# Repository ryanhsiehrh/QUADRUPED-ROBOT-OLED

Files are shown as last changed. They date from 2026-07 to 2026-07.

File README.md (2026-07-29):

# QUADRUPED-ROBOT-OLED
Quadruped robot powered by an Arduino Pro Micro (ATmega32U4). Operates on 5V power, utilizing 12 servo motors for inverse kinematics and an animated OLED display face through Software I2C.


##  What it does

* **Inverse Kinematics:** Calculates real-time 3D leg positions ($X, Y, Z$) across 12 servos (3 per leg) for smooth walking, turning, and custom body movements.
* **Animated OLED Face:** Runs an expression state machine on a 0.96 inch OLED display. The eyes pan side-to-side, blink every 3 seconds, and automatically close when the robot sits down.
* **Software I2C Communication:** Since the Pro Micro's hardware I2C pins (Pins 2 & 3) were already being used for servo signal lines, the OLED screen is driven via software I2C on analog pins `A0` (SDA) and `A1` (SCL).
* **50Hz Servo Interrupts:** Uses `FlexiTimer2` to keep servo updates running smoothly in the background without locking up the loop.
* **USB Serial Control:** Responds to string commands sent from the Arduino Serial Monitor at 9600 baud.

---

##  Hardware Setup & Pin Mapping

### Electronics
* **Board:** Arduino Pro Micro (ATmega32U4, 5V / 16MHz)
* **Servos:** 12x SG90 Micro Servos
* **Display:** 0.96" SSD1306 OLED Screen ($128 \times 64$, Yellow/Blue split)
* **Power:** External 5V power supply for the servos (common ground connected to the Arduino).
* **LM2596S Step Down Module** used to step down 12V power supply to 5V if needed

### Pinout Table

| Component | Function | Arduino Pro Micro Pin |
| :--- | :--- | :--- |
| **OLED Display** | **SDA** (Data) | **A0** *(Software I2C)* |
| **OLED Display** | **SCL** (Clock) | **A1** *(Software I2C)* |
| **Leg 0 (Back Left)** | Coxa / Femur / Tibia | Pins `2`, `3`, `4` |
| **Leg 1 (Front Left)**| Coxa / Femur / Tibia | Pins `5`, `6`, `7` |
| **Leg 2 (Back Right)** | Coxa / Femur / Tibia | Pins `8`, `9`, `10` |
| **Leg 3 (Front Right)**  | Coxa / Femur / Tibia | Pins `16`, `14`, `15` |

---

## PCB Design

* Simple 2-layer design with a solid ground plane on the back
* Uses barrel jack for power connection
* Specific area to hold the LM2596S Step Down Module
* Contains SPDT switch to toggle power to servo motors ON or OFF

**Schematic:**

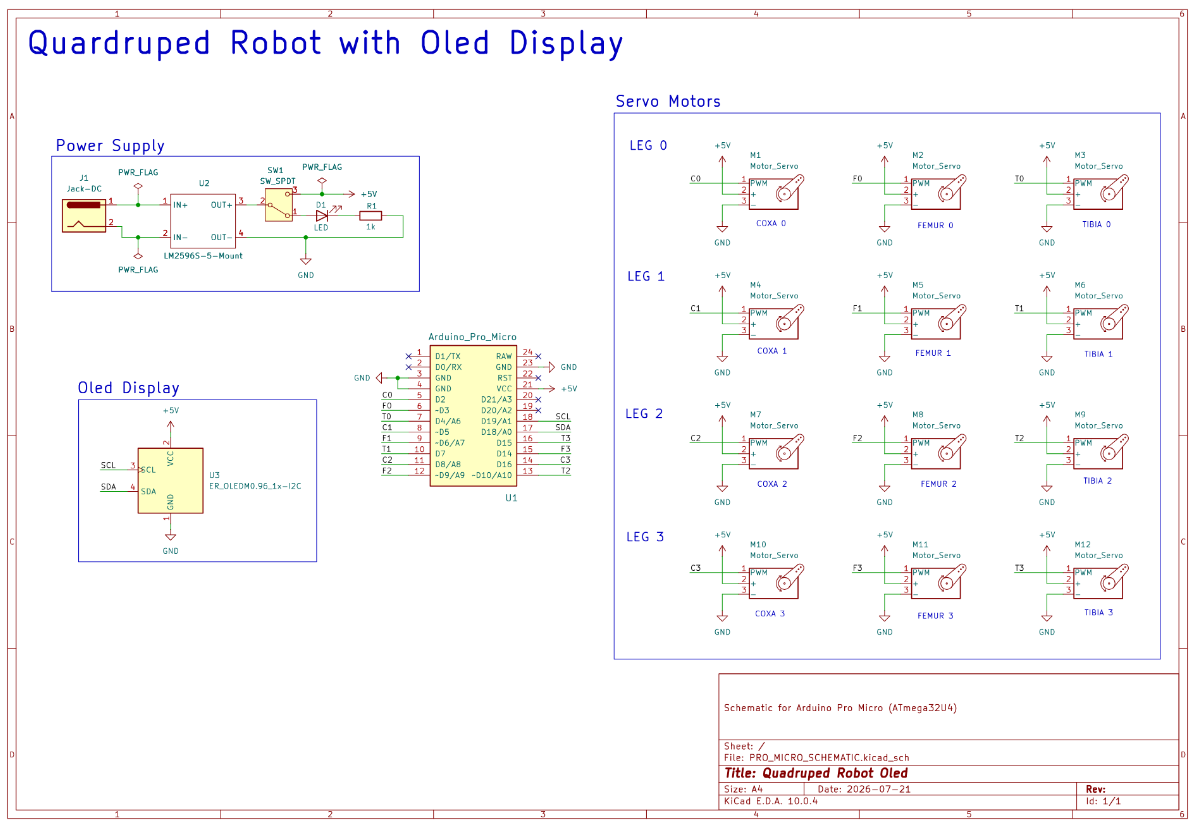
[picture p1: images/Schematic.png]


**PCB:**

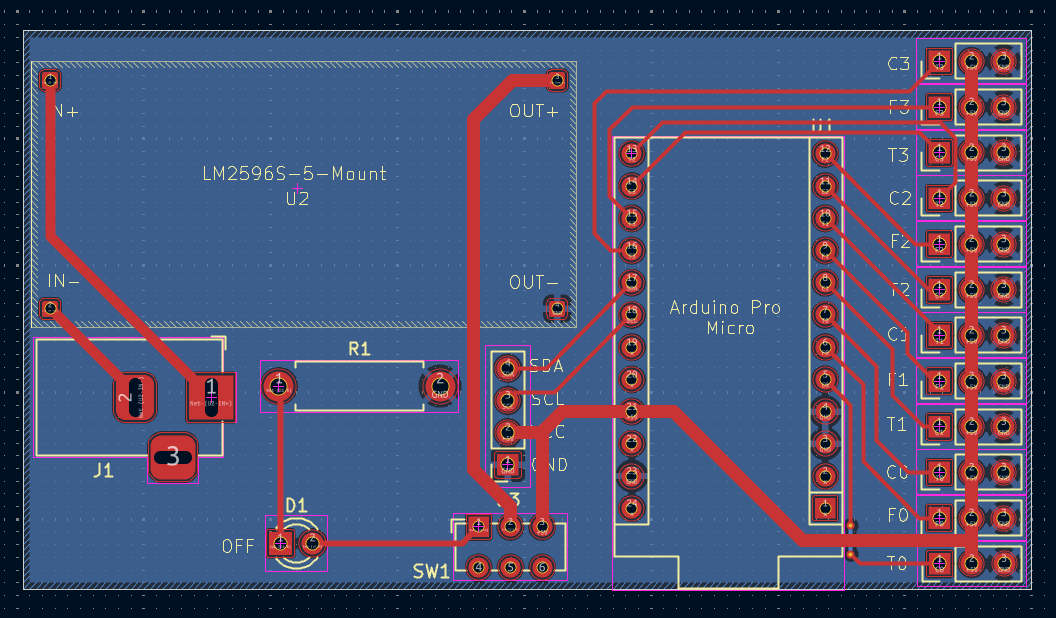
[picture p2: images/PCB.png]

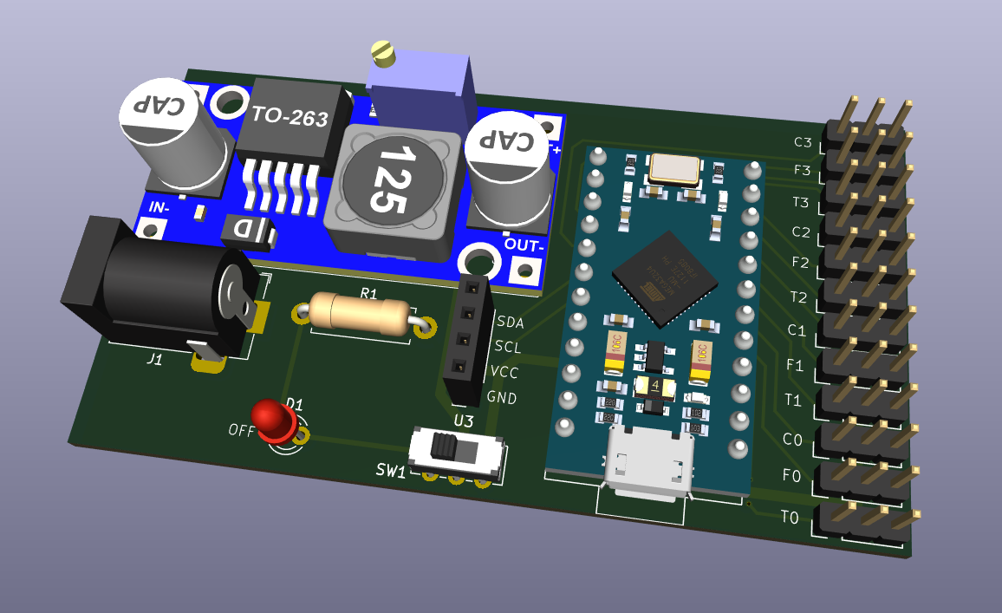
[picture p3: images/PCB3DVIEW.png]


---

##  Serial Commands

Set your Serial Monitor to **9600 Baud** and **Newline**. Type any of the following commands:

* `w 0 1` – Stand Up (wakes up face display)
* `w 0 0` – Sit Down (closes eyes on display)
* `w 1 x` – Walk Forward x steps
* `w 2 x` – Walk Backward x steps
* `w 3 x` – Turn Right x steps
* `w 4 x` – Turn Left x steps
* `w 5 x` – Hand Shake emote (x times)
* `w 6 x` – Hand Wave emote (x times)
* `w 7 x` – Side-to-Side body sway (x times)
* `w 8 x` – Bounce body emote (x times)
* `w 9 x` – Up and Down stretch (x times)

---

## Libraries

Install these via the Arduino Library Manager or online:

* `U8g2` (for operating OLED screen)
* `FlexiTimer2` (for 50Hz timer interrupts)
* `SerialCommand` (for parsing serial input strings)
* `Servo` (standard servo motor library)

---

## 3D Printed Parts

The chassis and leg components are based on [Regis Hsu's Spider Robot Design on Thingiverse](https://www.thingiverse.com/thing:1009659).

---

## How to Run

1. **Center Servos:** Before attaching the legs, upload `servo_90.ino` to set all 12 servos to their $90^\circ$ midpoint.
2. **Assemble:** Mount the leg horns at $90^\circ$ angles relative to the chassis.
3. **Upload Firmware:** Open `QUADRUPED-ROBOT-OLED.ino`, select **Arduino Leonardo**, and flash the sketch.
4. **Test:** Open Serial Monitor, make sure Newline is enabled, and send `w 0 1` to stand the robot up!

---

## Demo Video
[Watch the Quadruped Robot video here!](https://www.youtube.com/watch?v=7HYvcp7Kx8c)

---

## Credits

* Original base code by panerqiang@sunfounder.com (2015).
* Bluetooth remote and emote modifications by **RegisHsu** (2015).
* Pro Micro migration, custom movement emotes, software I2C OLED face animation, Kicad schematic and PCB developed by **Ryan Hsieh**.

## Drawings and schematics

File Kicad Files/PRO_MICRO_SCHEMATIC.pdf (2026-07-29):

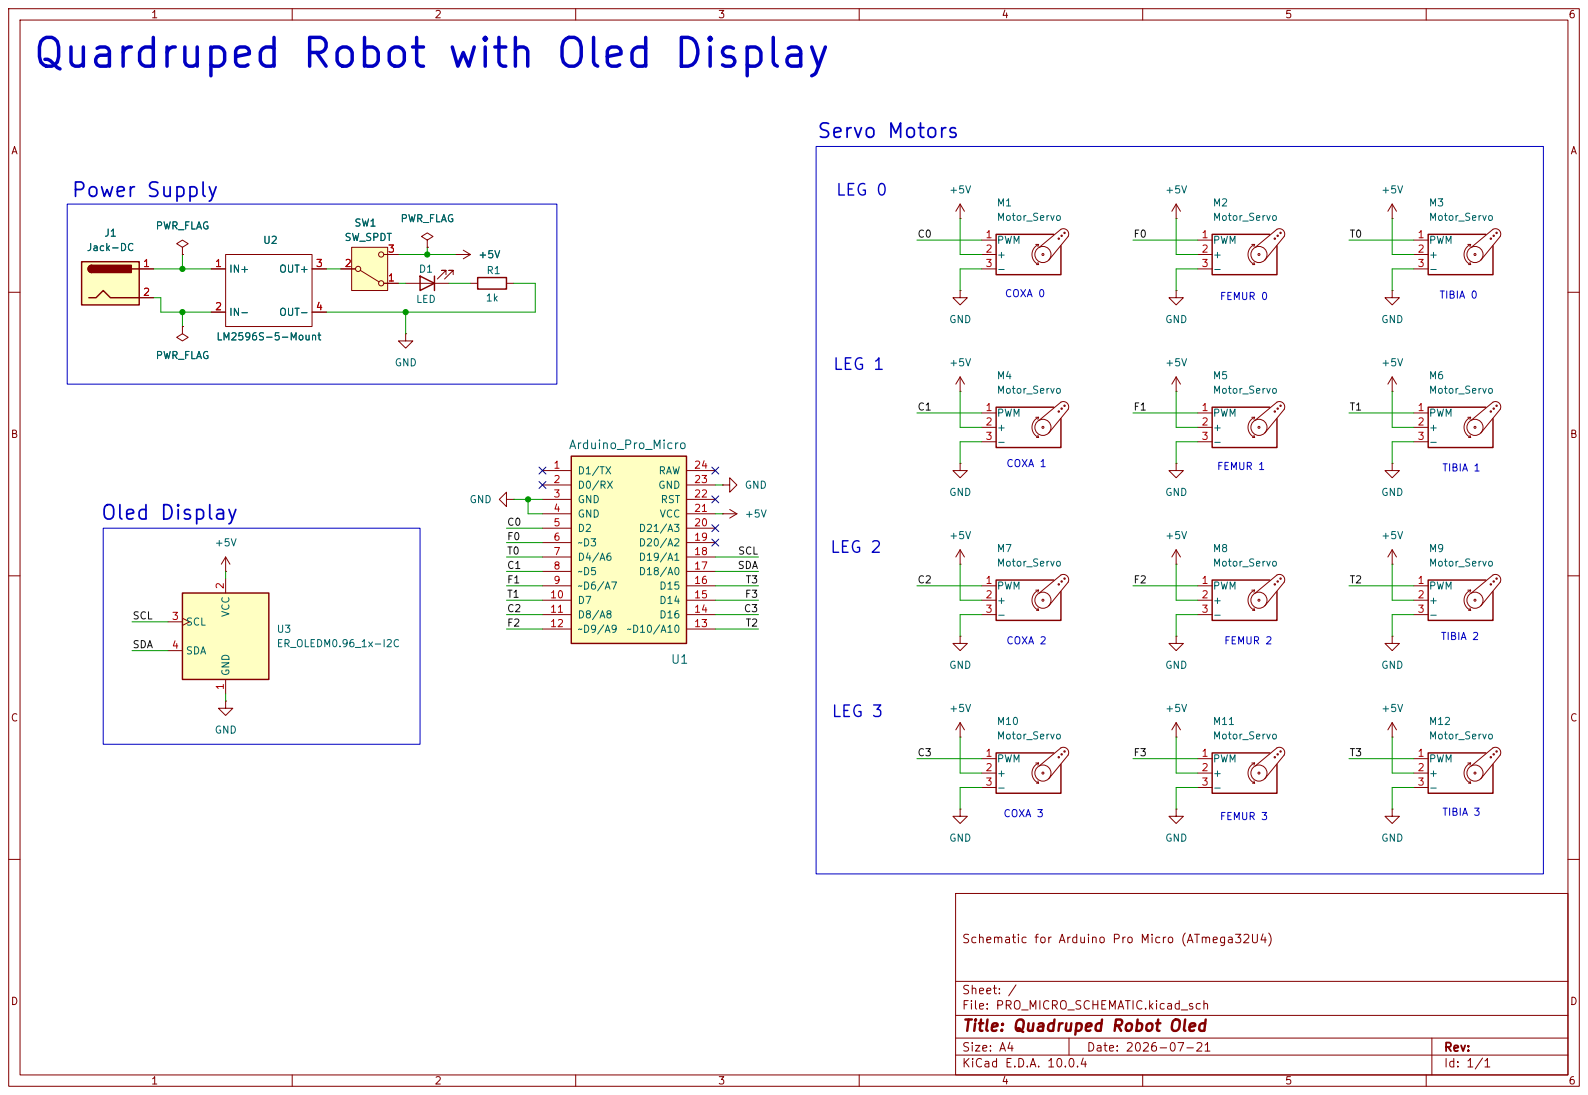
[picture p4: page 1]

F2 SCL Quardruped Robot with Oled Display

Schematic for Arduino Pro Micro (ATmega32U4)

Sheet: /
File: PRO_MICRO_SCHEMATIC.kicad_sch
Title: Quadruped Robot Oled

Size: A4 | Rev:
KiCad E.D.A. 10.0.4 | Id: 1/1

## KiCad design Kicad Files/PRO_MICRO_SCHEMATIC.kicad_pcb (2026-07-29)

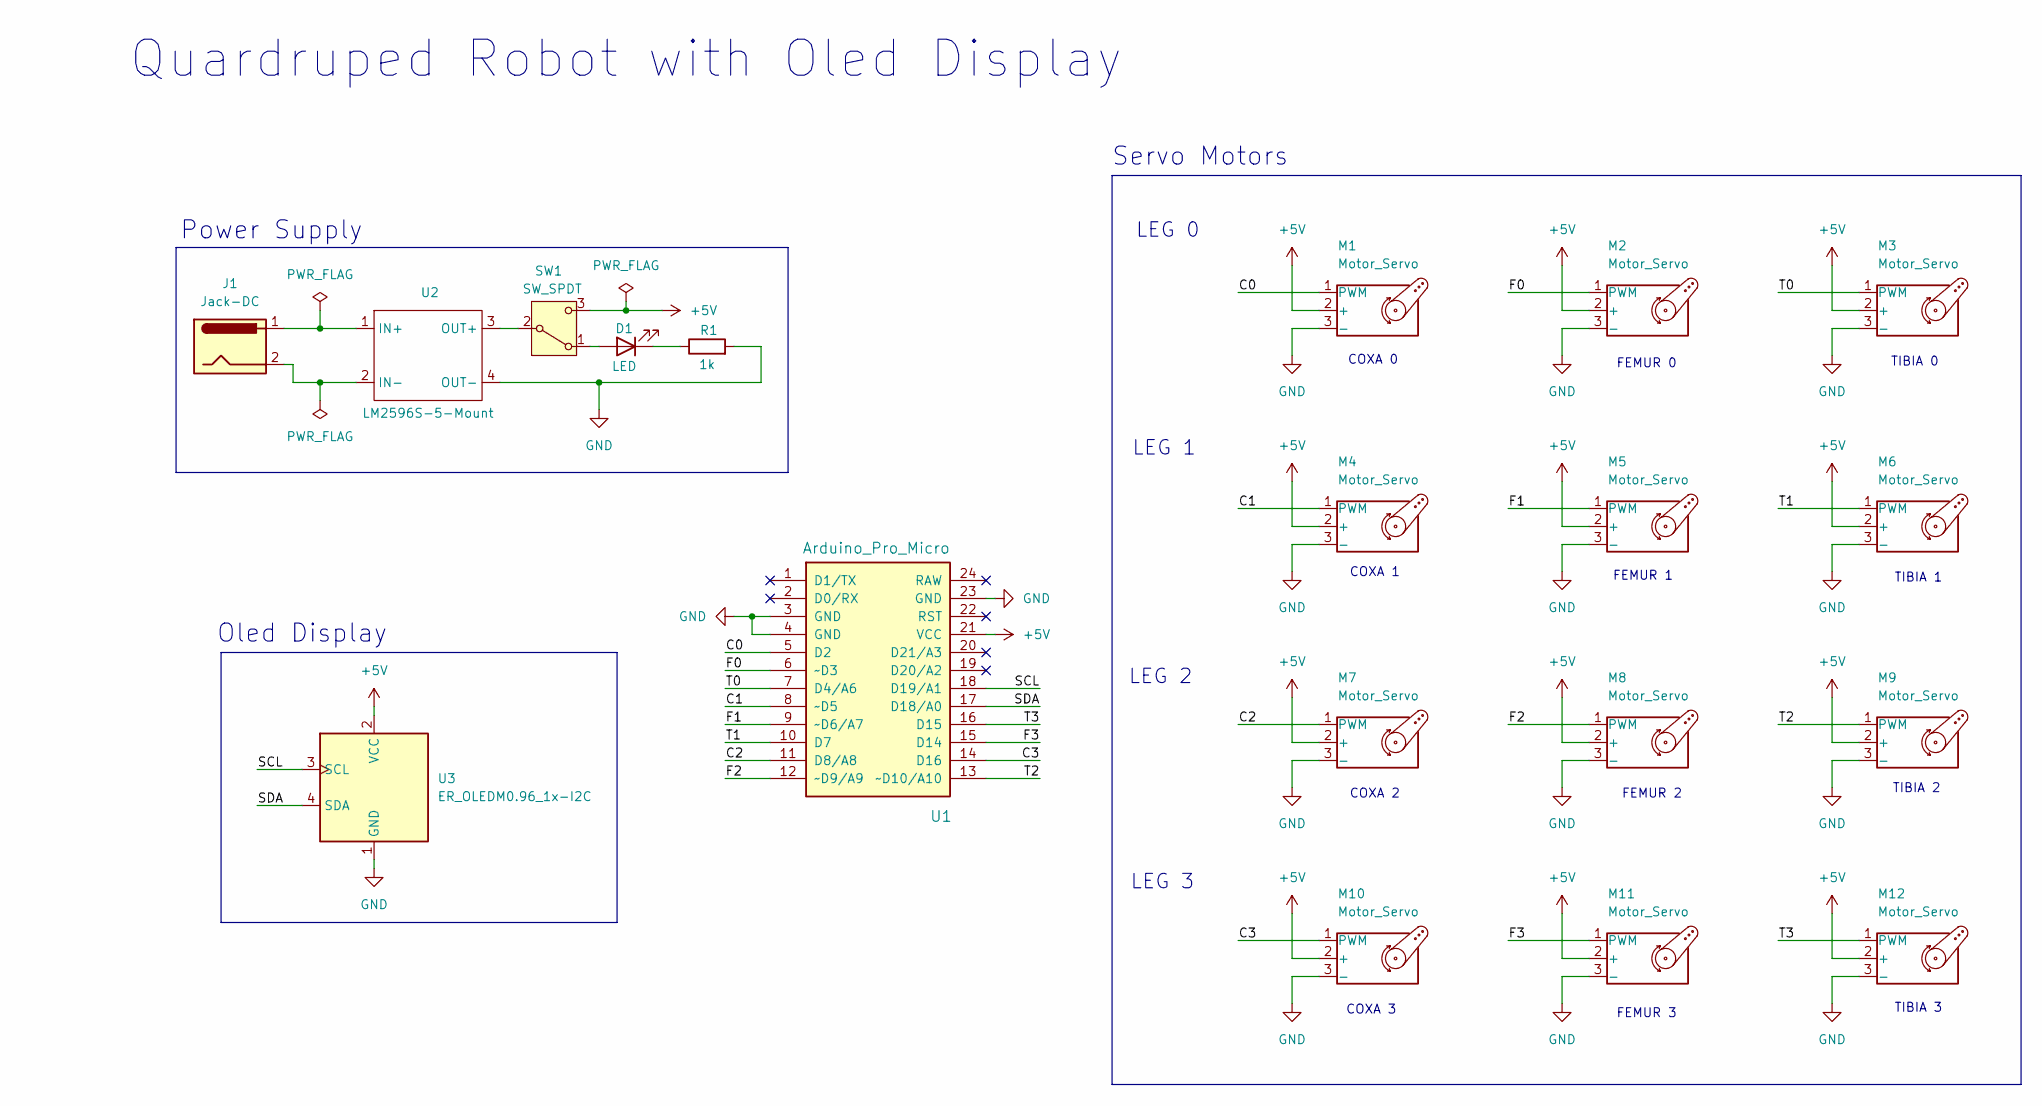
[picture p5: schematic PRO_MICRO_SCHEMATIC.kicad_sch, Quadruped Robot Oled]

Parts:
D1: LED; LED_D3.0mm
J1: Jack-DC; BarrelJack_Horizontal
M1, M2, M3, M4, M5, M6, M7, M8, M9, M10, M11, M12: Motor_Servo; PinHeader_1x03_P2.54mm_Vertical
R1: 1k; R_Axial_DIN0411_L9.9mm_D3.6mm_P12.70mm_Horizontal
SW1: SW_SPDT; SW_E-Switch_EG1271_SPDT
U1: Arduino_Pro_Micro; Sparkfun_Pro_Micro
U2: LM2596S-5-Mount
U3: ER_OLEDM0.96_1x-I2C; PinSocket_1x04_P2.54mm_Vertical

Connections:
+5V: M1.2 (+), M2.2 (+), M3.2 (+), M4.2 (+), M5.2 (+), M6.2 (+), M7.2 (+), M8.2 (+), M9.2 (+), M10.2 (+), M11.2 (+), M12.2 (+), SW1.3 (C), U1.21 (VCC), U3.2 (VCC)
/C0: M1.1 (PWM), U1.5 (D2)
/C1: M4.1 (PWM), U1.8 (~D5)
/C2: M7.1 (PWM), U1.11 (D8/A8)
/C3: M10.1 (PWM), U1.14 (D16)
/F0: M2.1 (PWM), U1.6 (~D3)
/F1: M5.1 (PWM), U1.9 (~D6/A7)
/F2: M8.1 (PWM), U1.12 (~D9/A9)
/F3: M11.1 (PWM), U1.15 (D14)
/SCL: U1.18 (D19/A1), U3.3 (SCL)
/SDA: U1.17 (D18/A0), U3.4 (SDA)
/T0: M3.1 (PWM), U1.7 (D4/A6)
/T1: M6.1 (PWM), U1.10 (D7)
/T2: M9.1 (PWM), U1.13 (~D10/A10)
/T3: M12.1 (PWM), U1.16 (D15)
GND: M1.3 (-), M2.3 (-), M3.3 (-), M4.3 (-), M5.3 (-), M6.3 (-), M7.3 (-), M8.3 (-), M9.3 (-), M10.3 (-), M11.3 (-), M12.3 (-), R1.2, U1.3 (GND), U1.4 (GND), U1.23 (GND), U2.4 (OUT-), U3.1 (GND)
unnamed: D1.2 (A), SW1.1 (A)
unnamed: D1.1 (K), R1.1
unnamed: SW1.2 (B), U2.3 (OUT+)
unnamed: J1.1, U2.1 (IN+)
unnamed: J1.2, U2.2 (IN-)

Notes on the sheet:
FEMUR 3
Oled Display
Quardruped Robot with Oled Display
TIBIA 3
LEG 0
FEMUR 0
COXA 1
LEG 3
TIBIA 0
FEMUR 2
FEMUR 1
COXA 3
COXA 0
Power Supply
TIBIA 2
TIBIA 1
LEG 1
Servo Motors
COXA 2
LEG 2

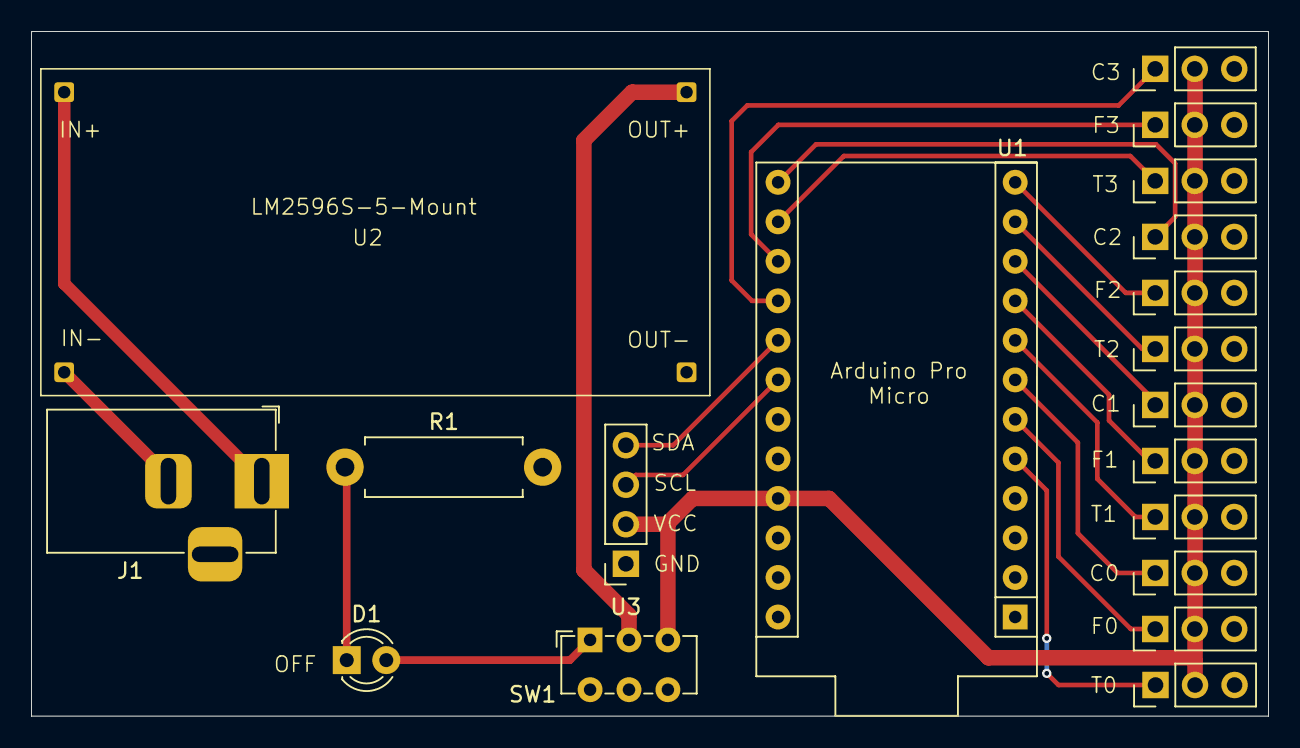
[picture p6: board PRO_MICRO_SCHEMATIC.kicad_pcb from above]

Board: 2 copper layers, 79.5 x 44.0 mm, 19 parts (0 on the bottom side), 21 nets.

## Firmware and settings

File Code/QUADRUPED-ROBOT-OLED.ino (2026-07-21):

/* =============================================================================
 *  Project:   Quadruped Spider Robot Oled 
 *  Author:    Ryan Hsieh
 *  Board:     Arduino Pro Micro (ATmega32U4)
 *  Features:  - USB Serial Command Control
 *             - Software I2C 0.96" OLED Face Display (SDA: A0, SCL: A1)
 *             - 3 Custom Motion Emotes (Side-to-Side, Bounce, Up & Down)
 *             - Non-blocking Animated Face with Eye Blinking
 *             - Additional code comments for better understanding
 * =============================================================================
 *  Original Base Code:
 *  - Author: panerqiang@sunfounder.com (2015-01-27)
 *  - Modified by Regis for spider remote control (2015-09-26)
 * ============================================================================= */

/* Includes ------------------------------------------------------------------*/
#include <Servo.h>        //to define and control servos
#include <FlexiTimer2.h>  //to set a timer to manage all servos
// RegisHsu, remote control
#include <SerialCommand.h>
SerialCommand SCmd;  // The demo SerialCommand object
#include <U8g2lib.h> //for oled screen
//software I2C setup: A1 = SCL, A0 = SDA
U8G2_SSD1306_128X64_NONAME_F_SW_I2C u8g2(U8G2_R0, /* clock=*/ A1, /* data=*/ A0, /* reset=*/ U8X8_PIN_NONE);

/* Oled screen ----------------------------------------------------------------*/
unsigned long lastBlinkTime = 0;
const unsigned long blinkInterval = 3000; // blink every 3s
const unsigned long blinkDuration = 120;  // 120ms blink time

int currentX = 0;
int state = 0; // 0: Center Pause, 1: Pan Left, 2: Pause Left, 3: Pan Right, 4: Pause Right, 5: Pan Center
unsigned long stateTimer = 0;

// TRACKS SITTING STATE 
bool isSitting = false; 

void drawFace(int xOff, bool isBlinking);

/* Servos --------------------------------------------------------------------*/
//define 12 servos for 4 legs
Servo servo[4][3];
//define servos' ports
const int servo_pin[4][3] = { { 2, 3, 4 }, { 5, 6, 7 }, { 8, 9, 10 }, { 16, 14, 15 } };
/* Size of the robot ---------------------------------------------------------*/
const float length_a = 55;     //femure
const float length_b = 77.5;   //tibia
const float length_c = 27.5;   //coxa
const float length_side = 71;  //length+width
const float z_absolute = -28;  //minimum height
/* Constants for movement ----------------------------------------------------*/
const float z_default = -50, z_up = -30, z_boot = z_absolute;
//standing and clearance height for moving
const float x_default = 62, x_offset = 0;  //coxa to tibia distance (sideways)
const float y_start = 0, y_step = 40;      //step distance
/* variables for movement ----------------------------------------------------*/
volatile float site_now[4][3];     //real-time coordinates of the end of each leg
volatile float site_expect[4][3];  //expected coordinates of the end of each leg
float temp_speed[4][3];            //each axis' speed, needs to be recalculated before each movement
float move_speed;                  //movement speed
float speed_multiple = 1;          //movement speed multiple
const float spot_turn_speed = 4;
const float leg_move_speed = 8;
const float body_move_speed = 3;
const float stand_seat_speed = 1;
volatile int rest_counter;  //+1/0.02s, for automatic rest
//functions' parameter
const float KEEP = 255;
//define PI for calculation
const float pi = 3.1415926;
/* Constants for turn --------------------------------------------------------*/
//temp length
const float temp_a = sqrt(pow(2 * x_default + length_side, 2) + pow(y_step, 2));
//diagonal length from whole x length and y_step(40)
const float temp_b = 2 * (y_start + y_step) + length_side;
//front to back distance w/ body width
const float temp_c = sqrt(pow(2 * x_default + length_side, 2) + pow(2 * y_start + y_step + length_side, 2));
//entire diagonal length from top left to bottom right
const float temp_alpha = acos((pow(temp_a, 2) + pow(temp_b, 2) - pow(temp_c, 2)) / 2 / temp_a / temp_b);
//law of cos for angle of rotation during a step
//site for turn marking 4 leg locations for rotation left/right
const float turn_x1 = (temp_a - length_side) / 2;                        //64
const float turn_y1 = y_start + y_step / 2;                              //20
const float turn_x0 = turn_x1 - temp_b * cos(temp_alpha);                //59.61
const float turn_y0 = temp_b * sin(temp_alpha) - turn_y1 - length_side;  //39.73
/* ---------------------------------------------------------------------------*/

/*
  - setup function
   ---------------------------------------------------------------------------*/
void setup() {
  //start serial for debug
  Serial.begin(9600);
  while (!Serial); // Guard for Pro Micro USB stack
  Serial.println("Robot starts initialization");

  // RegisHsu, remote control
  // Setup callbacks for SerialCommand commands
  // action command 0-6,
  // w 0 1: stand
  // w 0 0: sit
  // w 1 x: forward x step
  // w 2 x: back x step
  // w 3 x: right turn x step
  // w 4 x: left turn x step
  // w 5 x: hand shake x times
  // w 6 x: hand wave x times
  SCmd.addCommand("w", action_cmd);

  SCmd.setDefaultHandler(unrecognized);

  //initialize default parameter
  set_site(0, x_default - x_offset, y_start + y_step, z_boot);  //set_site(0, 62, 40, -28)
  set_site(1, x_default - x_offset, y_start + y_step, z_boot);  //set_site(1, 62, 40, -28)
  set_site(2, x_default + x_offset, y_start, z_boot);           //set_site(2, 62, 0, -28)
  set_site(3, x_default + x_offset, y_start, z_boot);           //set_site(3, 62, 0, -28)
  for (int i = 0; i < 4; i++) {
    for (int j = 0; j < 3; j++) {
      site_now[i][j] = site_expect[i][j];  //set now to expected
    }
  }
  //start servo service
  FlexiTimer2::set(20, servo_service);  //checks servo every 20 seeconds
  FlexiTimer2::start();
  Serial.println("Servo service started");
  //initialize servos
  servo_attach();  //sets up all initial servo positions
  Serial.println("Servos initialized");
  Serial.println("Robot initialization Complete");

  //Oled display setup
  u8g2.begin();
  u8g2.setBusClock(400000); 
  lastBlinkTime = millis();
  stateTimer = millis();
}


void servo_attach(void) {
  for (int i = 0; i < 4; i++) {
    for (int j = 0; j < 3; j++) {
      servo[i][j].attach(servo_pin[i][j]);
      //turns on pusle width modulation to the pin to go to initial positon
      delay(100);
    }
  }
}

void servo_detach(void) {
  for (int i = 0; i < 4; i++) {
    for (int j = 0; j < 3; j++) {
      servo[i][j].detach();
      delay(100);
    }
  }
}
/*
  - loop function
   ---------------------------------------------------------------------------*/

void loop() {
  SCmd.readSerial();

  //Code for OLED display face
  unsigned long now = millis();

  // 1. Blink checker
  if (now - lastBlinkTime >= blinkInterval + blinkDuration) {
    lastBlinkTime = now;
  }
  // If sitting, force eyes closed (isBlinking = true); otherwise check timer
  bool isBlinking = isSitting || (now - lastBlinkTime >= blinkInterval);

  // 2. Moving face (pauses movement if sitting)
  if (!isSitting) {
    switch (state) {
      case 0: // Pause at Center for 4 Seconds
        currentX = 0;
        if (now - stateTimer >= 4000) {
          state = 1; // Start panning Left
        }
        break;

      case 1: // Pan left 
        currentX -= 3;
        if (currentX <= -15) {
          currentX = -15;
          state = 2;
          stateTimer = now;
        }
        break;

      case 2: // Brief pause at eft
        if (now - stateTimer >= 200) {
          state = 3; // Start panning Right
        }
        break;

      case 3: // Pan right 
        currentX += 3;
        if (currentX >= 15) {
          currentX = 15;
          state = 4;
          stateTimer = now;
        }
        break;

      case 4: // Brief pause at right
        if (now - stateTimer >= 200) {
          state = 5; // Return to Center
        }
        break;

      case 5: // Pan back to center 
        currentX -= 3;
        if (currentX <= 0) {
          currentX = 0;
          state = 0; // Stay in center for 4s again
          stateTimer = now;
        }
        break;
    }
  } else {
    // Return eyes to center while sitting
    currentX = 0; 
  }

  drawFace(currentX, isBlinking);
  delay(10);
}


// OLED DISPLAY FACE DRAWING
void drawFace(int xOff, bool isBlinking) {
  u8g2.clearBuffer();

  // YELLOW ZONE (Y: 0 to 15) Eyebrows
  u8g2.drawLine(25 + xOff, 13, 45 + xOff, 8);   
  u8g2.drawLine(25 + xOff, 14, 45 + xOff, 9);   
  u8g2.drawLine(103 + xOff, 13, 83 + xOff, 8); 
  u8g2.drawLine(103 + xOff, 14, 83 + xOff, 9); 

  // BLUE ZONE (Y: 17 to 63) Round Eyes vs. Closed Lines
  if (isBlinking) {
    // Closed eyes (Used during 120ms blinks AND throughout sitting state)
    u8g2.drawHLine(25 + xOff, 36, 20); 
    u8g2.drawHLine(83 + xOff, 36, 20); 
  } else {
    // Open eyes
    u8g2.drawDisc(35 + xOff, 36, 10); 
    u8g2.drawDisc(93 + xOff, 36, 10); 
  }

  u8g2.sendBuffer();
}

// tests out all functions, call in setup or loop to test
void do_test(void) {

  Serial.println("Stand");
  stand();
  delay(2000);
  Serial.println("Step forward");
  step_forward(5);
  delay(2000);
  Serial.println("Step back");
  step_back(5);
  delay(2000);
  Serial.println("Turn left");
  turn_left(5);
  delay(2000);
  Serial.println("Turn right");
  turn_right(5);
  delay(2000);
  Serial.println("Hand wave");
  hand_wave(3);
  delay(2000);
  Serial.println("Hand wave");
  hand_shake(3);
  delay(2000);
  Serial.println("Side to side");
  side_to_side(5);
  delay(2000);
  Serial.println("Bounce");
  bounce(5);
  delay(2000);
  Serial.println("Up and down");
  updown(5);
  delay(2000);

  Serial.println("Sit");
  sit();
  delay(5000);
}

// RegisHsu
// w 0 1: stand
// w 0 0: sit
// w 1 x: forward x step
// w 2 x: back x step
// w 3 x: right turn x step
// w 4 x: left turn x step
// w 5 x: hand shake x times
// w 6 x: hand wave x times

// Ryan Hsieh
// w 7 x: side to side x times
// w 8 x: bounce x times
// w 9 x: up and down x times

#define W_STAND_SIT 0
#define W_FORWARD 1
#define W_BACKWARD 2
#define W_LEFT 3
#define W_RIGHT 4
#define W_SHAKE 5
#define W_WAVE 6
#define W_SIDETOSIDE 7
#define W_BOUNCE 8
#define W_UPDOWN 9

void action_cmd(void) {
  char *arg;
  int action_mode, n_step;
  Serial.println("Action:");
  arg = SCmd.next();
  action_mode = atoi(arg);
  arg = SCmd.next();
  n_step = atoi(arg);

  // Starts up face on any command except sit (w 0 0)
  if (action_mode != W_STAND_SIT || n_step == 1) {
    isSitting = false;
  }

  switch (action_mode) {
    case W_FORWARD:
      Serial.println("Step forward");
      if (!is_stand())
        stand();
      step_forward(n_step);
      break;
    case W_BACKWARD:
      Serial.println("Step back");
      if (!is_stand())
        stand();
      step_back(n_step);
      break;
    case W_LEFT:
      Serial.println("Turn left");
      if (!is_stand())
        stand();
      turn_left(n_step);
      break;
    case W_RIGHT:
      Serial.println("Turn right");
      if (!is_stand())
        stand();
      turn_right(n_step);
      break;
    case W_STAND_SIT:
      Serial.println("1:up,0:dn");
      if (n_step)
        stand();
      else
        sit();
      break;
    case W_SHAKE:
      Serial.println("Hand shake");
      hand_shake(n_step);
      break;
    case W_WAVE:
      Serial.println("Hand wave");
      hand_wave(n_step);
      break;

    case W_SIDETOSIDE:
      Serial.println("Side to side");
      if (!is_stand())
        stand();
      side_to_side(n_step);
      break;
    case W_BOUNCE:
      Serial.println("Bounce");
      if (!is_stand())
        stand();
      bounce(n_step);
      break;
    case W_UPDOWN:
      Serial.println("Up and down");
      if (!is_stand())
        stand();
      updown(n_step);
      break;

    default:
      Serial.println("Error");
      break;
  }
}

// This gets set as the default handler, and gets called when no other command matches.
void unrecognized(const char *command) {
  Serial.println("Unknown command");
}

/*
  - is_stand
   ---------------------------------------------------------------------------*/
bool is_stand(void) {

  if (site_now[0][2] == z_default)
    return true;
  else
    return false;
}

/*
  - sit
  - blocking function
   ---------------------------------------------------------------------------*/
void sit(void) {
  isSitting = true; // Makes eyes closed on display

  move_speed = stand_seat_speed;
  for (int leg = 0; leg < 4; leg++) {
    set_site(leg, KEEP, KEEP, z_boot);  //changes z to sit
  }
  wait_all_reach();  //wait for all legs to reach new position
}

/*
  - stand
  - blocking function
   ---------------------------------------------------------------------------*/
void stand(void) {
  isSitting = false; // Opens eyes and starts panning/blinking
  move_speed = stand_seat_speed;
  for (int leg = 0; leg < 4; leg++) {
    set_site(leg, KEEP, KEEP, z_default);  //changes z to stand
  }
  wait_all_reach();  //wait for all legs to reach new position
}


/*
  - spot turn to left
  - blocking function
  - parameter step steps wanted to turn
   ---------------------------------------------------------------------------*/
void turn_left(unsigned int step) {
  move_speed = spot_turn_speed;
  while (step-- > 0) {
    if (site_now[3][1] == y_start) {
      //leg 3&1 move
      set_site(3, x_default + x_offset, y_start, z_up);
      wait_all_reach();

      set_site(0, turn_x1 - x_offset, turn_y1, z_default);
      set_site(1, turn_x0 - x_offset, turn_y0, z_default);
      set_site(2, turn_x1 + x_offset, turn_y1, z_default);
      set_site(3, turn_x0 + x_offset, turn_y0, z_up);
      wait_all_reach();

      set_site(3, turn_x0 + x_offset, turn_y0, z_default);
      wait_all_reach();

      set_site(0, turn_x1 + x_offset, turn_y1, z_default);
      set_site(1, turn_x0 + x_offset, turn_y0, z_default);
      set_site(2, turn_x1 - x_offset, turn_y1, z_default);
      set_site(3, turn_x0 - x_offset, turn_y0, z_default);
      wait_all_reach();

      set_site(1, turn_x0 + x_offset, turn_y0, z_up);
      wait_all_reach();

      set_site(0, x_default + x_offset, y_start, z_default);
      set_site(1, x_default + x_offset, y_start, z_up);
      set_site(2, x_default - x_offset, y_start + y_step, z_default);
      set_site(3, x_default - x_offset, y_start + y_step, z_default);
      wait_all_reach();

      set_site(1, x_default + x_offset, y_start, z_default);
      wait_all_reach();
    } else {
      //leg 0&2 move
      set_site(0, x_default + x_offset, y_start, z_up);
      wait_all_reach();

      set_site(0, turn_x0 + x_offset, turn_y0, z_up);
      set_site(1, turn_x1 + x_offset, turn_y1, z_default);
      set_site(2, turn_x0 - x_offset, turn_y0, z_default);
      set_site(3, turn_x1 - x_offset, turn_y1, z_default);
      wait_all_reach();

      set_site(0, turn_x0 + x_offset, turn_y0, z_default);
      wait_all_reach();

      set_site(0, turn_x0 - x_offset, turn_y0, z_default);
      set_site(1, turn_x1 - x_offset, turn_y1, z_default);
      set_site(2, turn_x0 + x_offset, turn_y0, z_default);
      set_site(3, turn_x1 + x_offset, turn_y1, z_default);
      wait_all_reach();

      set_site(2, turn_x0 + x_offset, turn_y0, z_up);
      wait_all_reach();

      set_site(0, x_default - x_offset, y_start + y_step, z_default);
      set_site(1, x_default - x_offset, y_start + y_step, z_default);
      set_site(2, x_default + x_offset, y_start, z_up);
      set_site(3, x_default + x_offset, y_start, z_default);
      wait_all_reach();

      set_site(2, x_default + x_offset, y_start, z_default);
      wait_all_reach();
    }
  }
}

/*
  - spot turn to right
  - blocking function
  - parameter step steps wanted to turn
   ---------------------------------------------------------------------------*/
void turn_right(unsigned int step) {
  move_speed = spot_turn_speed;
  while (step-- > 0) {
    if (site_now[2][1] == y_start) {
      //leg 2&0 move

      //lift leg 2
      // Leg 2: X = 62mm,  Y = 0mm,   Z = -30mm (Air)
      set_site(2, x_default + x_offset, y_start, z_up);
      wait_all_reach();

      //shift body weight
      // Leg 0: X = 59.61mm, Y = 39.73mm, Z = -50mm (Ground)
      // Leg 1: X = 64.12mm, Y = 20.00mm, Z = -50mm (Ground)
      // Leg 2: X = 59.61mm, Y = 39.73mm, Z = -30mm (Air)
      // Leg 3: X = 64.12mm, Y = 20.00mm, Z = -50mm (Ground)
      set_site(0, turn_x0 - x_offset, turn_y0, z_default);
      set_site(1, turn_x1 - x_offset, turn_y1, z_default);
      set_site(2, turn_x0 + x_offset, turn_y0, z_up);
      set_site(3, turn_x1 + x_offset, turn_y1, z_default);
      wait_all_reach();

      //plant leg 2
      // Leg 2: X = 59.61mm, Y = 39.73mm, Z = -50mm (Ground)
      set_site(2, turn_x0 + x_offset, turn_y0, z_default);
      wait_all_reach();

      //pivot the body
      // Leg 0: X = 59.61mm, Y = 39.73mm, Z = -50mm (Ground)
      // Leg 1: X = 64.12mm, Y = 20.00mm, Z = -50mm (Ground)
      // Leg 2: X = 59.61mm, Y = 39.73mm, Z = -50mm (Ground)
      // Leg 3: X = 64.12mm, Y = 20.00mm, Z = -50mm (Ground)
      set_site(0, turn_x0 + x_offset, turn_y0, z_default);
      set_site(1, turn_x1 + x_offset, turn_y1, z_default);
      set_site(2, turn_x0 - x_offset, turn_y0, z_default);
      set_site(3, turn_x1 - x_offset, turn_y1, z_default);
      wait_all_reach();

      //lift leg 0
      // Leg 0: X = 59.61mm, Y = 39.73mm, Z = -30mm (Air)
      set_site(0, turn_x0 + x_offset, turn_y0, z_up);
      wait_all_reach();

      //move leg 0
      // Leg 0: X = 62.00mm, Y = 0mm,     Z = -30mm (Air)
      // Leg 1: X = 62.00mm, Y = 0mm,     Z = -50mm (Ground)
      // Leg 2: X = 62.00mm, Y = 40.00mm, Z = -50mm (Ground)
      // Leg 3: X = 62.00mm, Y = 40.00mm, Z = -50mm (Ground)
      set_site(0, x_default + x_offset, y_start, z_up);
      set_site(1, x_default + x_offset, y_start, z_default);
      set_site(2, x_default - x_offset, y_start + y_step, z_default);
      set_site(3, x_default - x_offset, y_start + y_step, z_default);
      wait_all_reach();

      //plant leg 0
      // Leg 0: X = 62.00mm, Y = 0mm,     Z = -50mm (Ground)
      set_site(0, x_default + x_offset, y_start, z_default);
      wait_all_reach();
    } else {
      //leg 1&3 move
      set_site(1, x_default + x_offset, y_start, z_up);
      wait_all_reach();

      set_site(0, turn_x1 + x_offset, turn_y1, z_default);
      set_site(1, turn_x0 + x_offset, turn_y0, z_up);
      set_site(2, turn_x1 - x_offset, turn_y1, z_default);
      set_site(3, turn_x0 - x_offset, turn_y0, z_default);
      wait_all_reach();

      set_site(1, turn_x0 + x_offset, turn_y0, z_default);
      wait_all_reach();

      set_site(0, turn_x1 - x_offset, turn_y1, z_default);
      set_site(1, turn_x0 - x_offset, turn_y0, z_default);
      set_site(2, turn_x1 + x_offset, turn_y1, z_default);
      set_site(3, turn_x0 + x_offset, turn_y0, z_default);
      wait_all_reach();

      set_site(3, turn_x0 + x_offset, turn_y0, z_up);
      wait_all_reach();

      set_site(0, x_default - x_offset, y_start + y_step, z_default);
      set_site(1, x_default - x_offset, y_start + y_step, z_default);
      set_site(2, x_default + x_offset, y_start, z_default);
      set_site(3, x_default + x_offset, y_start, z_up);
      wait_all_reach();

      set_site(3, x_default + x_offset, y_start, z_default);
      wait_all_reach();
    }
  }
}
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

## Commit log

2026-07-21 Add 3D Printed Parts section to README
    Added section about 3D printed parts and their source.
2026-07-28 Revise leg pin assignments and update credits
    Updated pin assignments for robot legs and added Kicad PCB development to credits.
2026-07-28 Create Kicad Files
2026-07-29 Edited files and added Kicad Files
    [PRO_MICRO_SCHEMATIC.kicad_pcb, PRO_MICRO_SCHEMATIC.kicad_sch]
